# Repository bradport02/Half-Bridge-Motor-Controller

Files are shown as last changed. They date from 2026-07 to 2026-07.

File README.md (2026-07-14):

# Half-Bridge Motor Controller — Driven ESAC

A custom half-bridge motor controller designed for a GreenPower electric race car, built for the Driven Electric Student Automotive Competition (ESAC) team. Designed to replace the team's off-the-shelf PORTER-10 controller, which limits continuous current to ~10-20 A.

**Status: design complete (schematic + 4-layer KiCad PCB), not yet fabricated or bench-tested.**

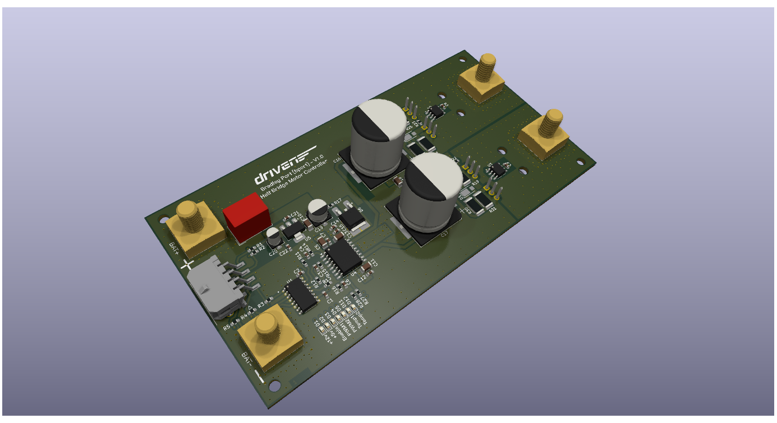
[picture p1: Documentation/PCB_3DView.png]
PCB 3D render

*3D render from KiCad — board has not yet been manufactured.*

## Purpose

Off-the-shelf controllers like the PORTER-10 are built for short current bursts and settle around 10-20 A continuous, which limits both acceleration off the line and sustained top speed. The goal was a controller capable of ~40 A continuous with a 120 A peak, giving the team a faster, more efficient motor drive and a platform that can be extended to regenerative braking in future.

## Target specification

- 120 A peak current draw
- ~40 A continuous draw
- 24 V system
- PWM input control
- On-board voltage regulation (24 V → 12 V → 5 V)

## How it works

The power stage is built around IRFB7440PbF N-channel MOSFETs (120 A rated), driven by a UCC21520 dual-channel gate driver. The UCC21520 takes PWM and control signals from a microcontroller and provides reinforced isolation between the low-voltage logic and the high-voltage power stage - protecting the control electronics from the transients typical of motor-drive environments. Its drive strength (4 A source / 6 A sink) is sized for fast, low-loss switching of the MOSFETs, and its programmable dead-time prevents shoot-through between high and low side.

Control interface:
- **PWM 1** — drive input
- **PWM 2** — regenerative braking input (architected for future use; not implemented in this revision. Both PWM inputs cannot be high simultaneously)
- **ENABLE** — logic-high enable

Signal isolation is handled by an ACSL-6400-50TE optocoupler for additional noise immunity.

## Connectors and I/O

- **Molex 43045-0806** — 8-pin signal input socket (PWM, enable, I²C, +12 V input)
- **Würth 7461098** — M8 metal lug connectors for battery and motor output, rated to 250 A

Two LM75 I²C temperature sensors monitor high-side and low-side MOSFET temperature, each with a programmable threshold that drives a status LED. The board has an onboard LED bank showing signal presence (PWM1/PWM2/Enable) and temperature-fault state at a glance.

## Voltage regulation

- **TSR-1-24120** steps 24 V down to 12 V, but only regulates correctly above ~15 V input.
- **UA78M05** regulates 12 V down to 5 V for logic.

**Known open item:** race telemetry shows battery voltage dropping below the TSR-1-24120's 15 V regulation floor during operation, which would drop the 12 V (and consequently 5 V) rail. A 12 V input pin is provided on the main connector as a workaround, but an external boost/always-available 12 V supply is the proposed fix and hasn't been implemented on this revision.

## PCB

Four-layer stack-up:
1. Power & signals
2. Continuous ground (noise isolation)
3. Ground & I²C
4. Power & signals

Specified for 2 oz copper on the outer layers for thermal dissipation, with extensive thermal vias. MOSFETs are oriented facing away from the board so they can be mounted to an external heatsink (as on the PORTER-10) rather than relying on the PCB alone for cooling.

Designed in KiCad across two schematic sheets — *Motor Controller* and *Power & Signals* — split for readability.

**This revision has no reverse-polarity protection.** This was a deliberate decision agreed with the ESAC team: the added complexity of full reverse-polarity protection at this current rating wasn't considered justified for this revision. BAT+ and BAT- are clearly marked on the silkscreen; correct wiring is required.

## Cost

Estimated production cost: **~£90/unit** (~£45 components, ~£45 PCB manufacture via JLCPCB). See the BOM for full component-level pricing.

## Future work

- Fabrication and bench testing of the current revision
- External 12 V supply to remove the low-battery-voltage regulation gap
- Regenerative braking implementation using the reserved PWM2 input

## Skills demonstrated

Power electronics design (MOSFET half-bridge, gate-drive isolation), 4-layer PCB design for high-current/thermal applications (KiCad), automotive/motorsport 12–24 V system design, I²C sensor integration, and BOM/cost engineering for a real production target.

## Author

Bradley Port — Designed for the Driven Electric Student Automotive Competition team.

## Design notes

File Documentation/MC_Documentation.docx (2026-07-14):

# Driven ESAC: Motor Controller

# Purpose:

Off the shelf motor controllers limit us as a team to how we can drive the motor. Typical controllers such as the PORTER-10 are designed to handle short current bursts but stabilise around 10/20amps. Our aim was to design a motor controller that would provide stable power at 40amps as well as have a peak current draw of 120amps. This will allow the car to accelerate off the line quicker but also maintain faster speeds. Additionally, designing a motor controller to our requirements allows us to be more efficient in how we drive the motor, but also add future functionality such as regenerative braking.

# Outcome:

After many conversations, we came up with a list of requirements and ultimately a specification to build the motor controller to. Some of the aims were:

- 120A peak current draw.
- ~40A continuous draw.
- Works with a 24v system.
- PWM input to control the motor.
- On-board voltage regulation.

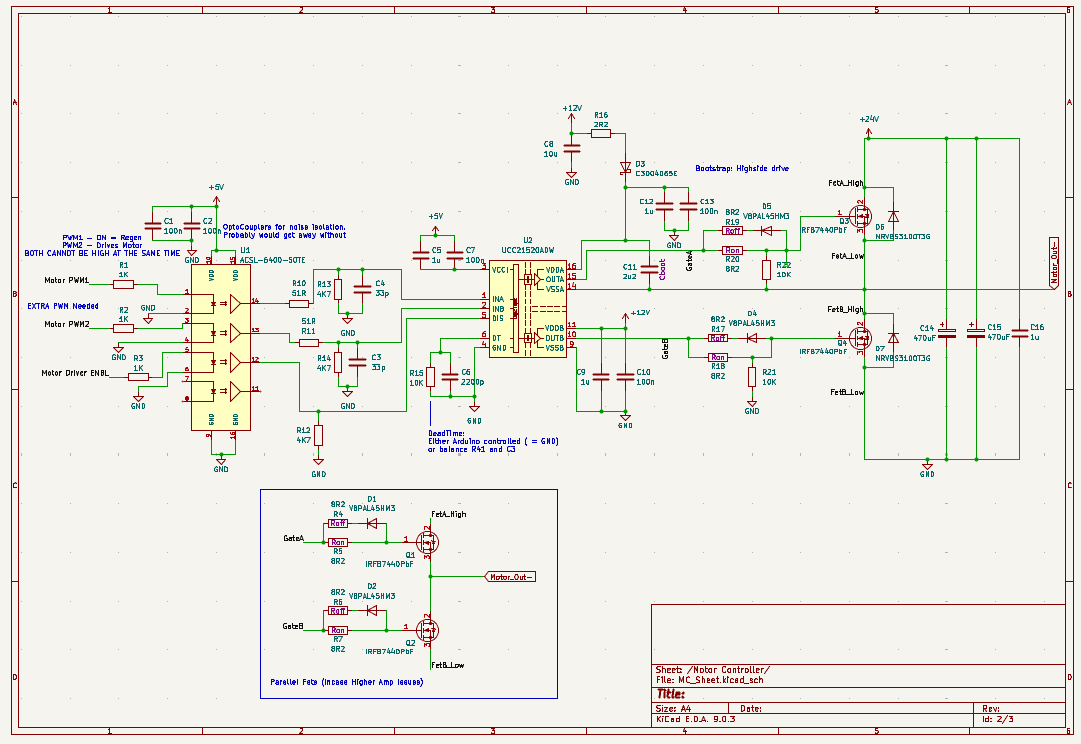
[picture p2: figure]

With these requirements, we build the following schematic.

## Key Components:

- UCC12520 Dual-Channel Gate Driver.
- ACSL-6400-50TE OptoCoupler.
- IRFB7440PbF 120A Mosfets

# How it works:

This motor controller circuit is designed to drive the motor in the driven race car, utilising the UCC21520 isolated gate driver and IFBN7440PbF N-channel MOSFETs. The UCC21520 receives PWM and control signals from a microcontroller and provides reinforced isolation between the low-voltage logic and high-voltage power stages, ensuring robust protection against the electrical transients, which are common in motor control environments. Its high current drive capability (4A source, 6A sink) enables fast and efficient switching of the IFBN7440PbF, which is optimized for low RDS and rapid response. This is critical for delivering precise torque and speed control when under dynamic racing conditions. The gate driver's programmable dead-time feature prevents shoot-through during switching, while its fast propagation delay supports high-frequency PWM for precise motor control. The signals required to drive this motor controller are:

- PWM 1 (INPUT A)
- PWM 2 (INPUT B)
- ENABLE (LOGIC HIGH)

# IO:

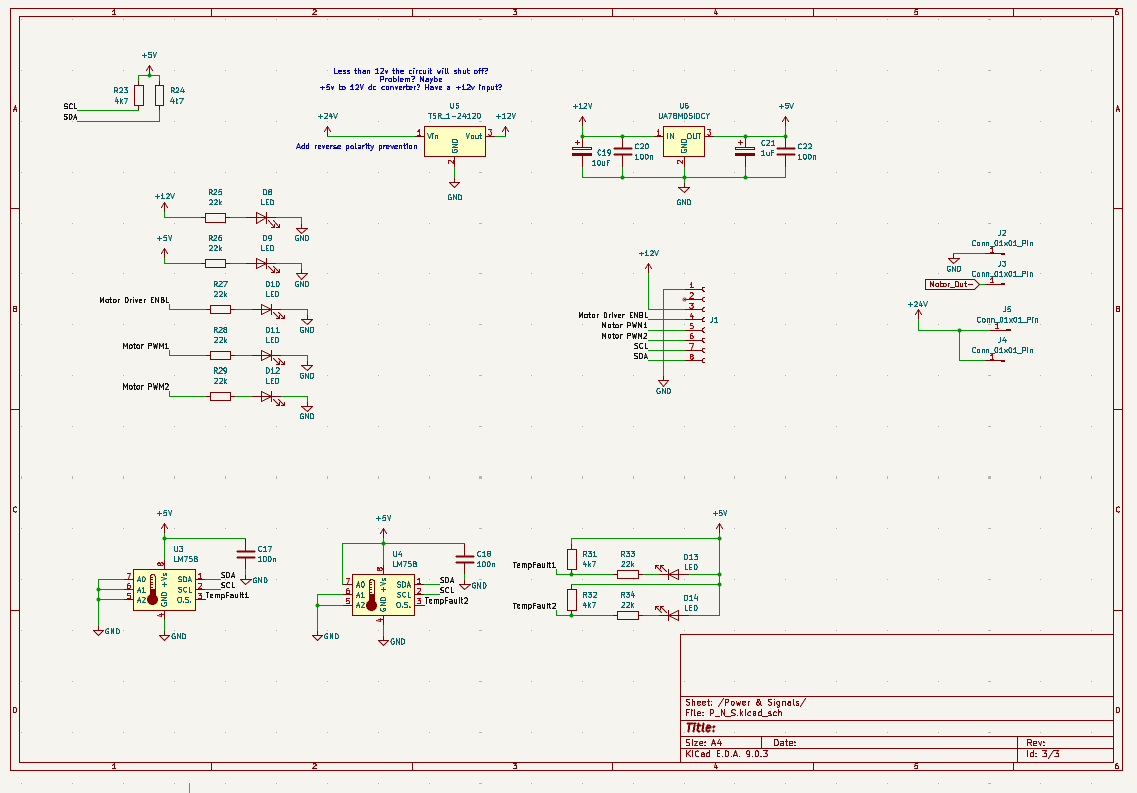
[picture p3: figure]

## Connectors:

MOLEX 43045-0806: 8 pin socket, this is where all the main inputs are provided to the board.

Wurth 7461098: M8 metal lug connections, allow the high-current connections from the battery and output to the motor. These can handle up to 250A.

## I2C:

The 8 pin socket (J1)has two inputs for the I2C signals, SCL (7) and SDA (8). These signals allow the two LM75 temperature sensors to be connected to the Arduino. The purpose of these is to provide a precise temperature of how hot the high and low side MOSFETs are. The LM75 can be programmed to have a threshold temperature in which an LED will illuminate.

## Voltage Regulation:

The board is designed to have an onboard TSR-1-24120 voltage regulator to step down the +24v to +12v. However, this IC only regulates when the input voltage is greater than +15v. From race data, it can be seen that the battery voltages drop well below this, I propose that there is an external voltage step up that can always provide +12v to the motor controller. Pin 3 on Connector J1 has a +12v input.

The +5v will always be regulated as long as there is a +12v rail present. The 5v regulator is a UA78M05.

# PCB:

The PCB has a four layer stack up:

1. Power & Signals.
2. Continuous Ground (Noise Isolation)
3. Ground and I2C.
4. Power and Signals.

The board MUST be manufactured with a 2Oz copper outer layers. This will help with thermal dissipation and is what the board has been designed to handle. The PCB has been designed to be as thermally efficient as possible, with many thermal vias. The MOSFETS face away from the PCB, so that they can be mounted to an external heatsink and keep the board cooler. See the PORTER-10 for an example. A sufficient heatsink will need to be manufactured.

THIS PCB HAS NO REVERSE POLARITY PROTECTION. From discussions with the ESAC Team we felt that the necessary complexity of protecting this device from reverse polarity was not required. Please take caution when powering this device and ensure that is has been wired correctly. There is BAT+ and BAT- labels as well as big ‘+’ and ‘-‘ idents on the silkscreen.

## Layer Stackup:

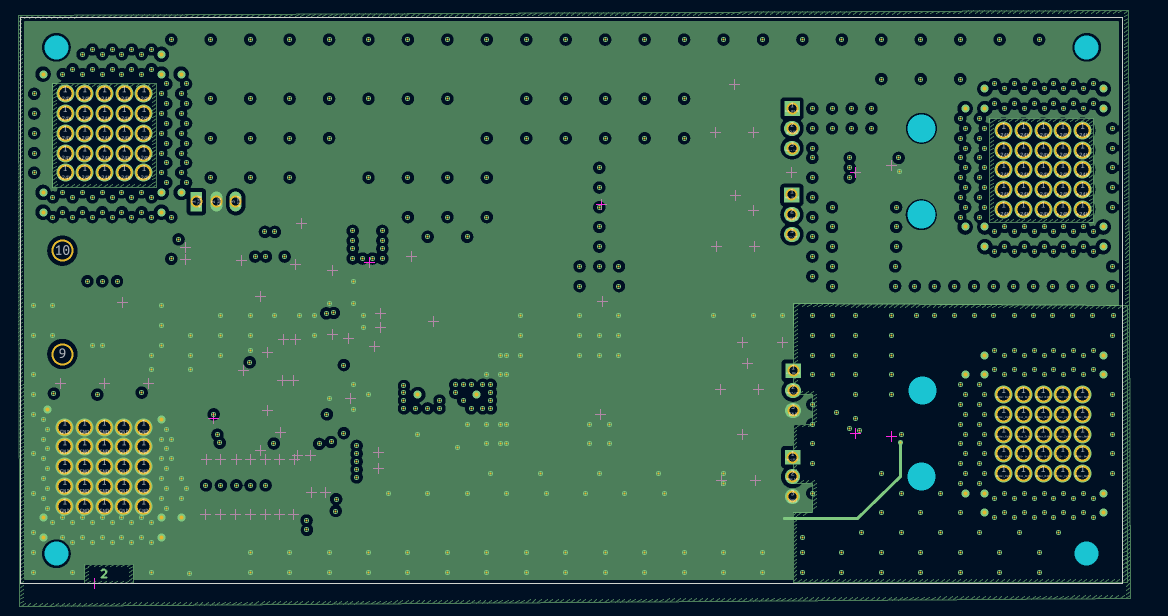
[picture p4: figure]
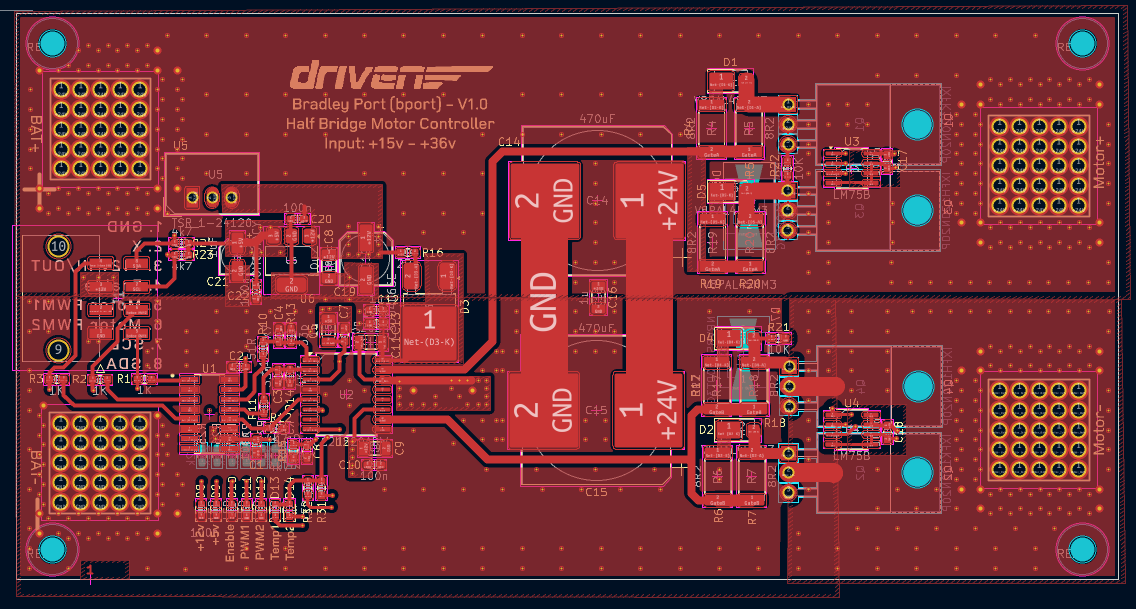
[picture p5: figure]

Layer 1:

Layer 2:

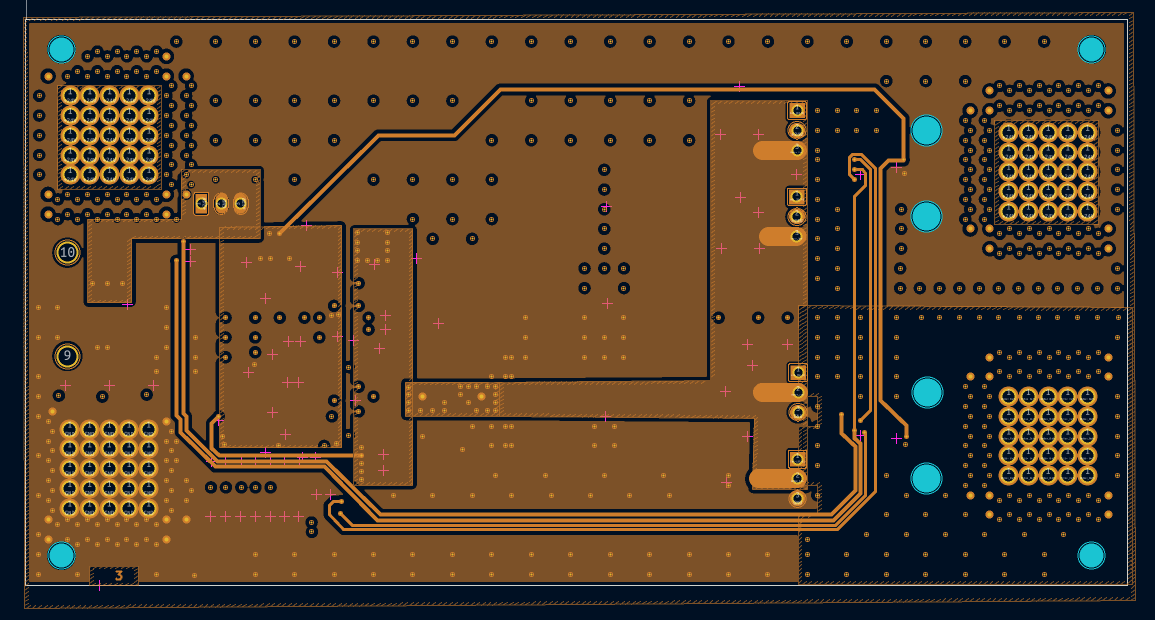
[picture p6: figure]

Layer 3:

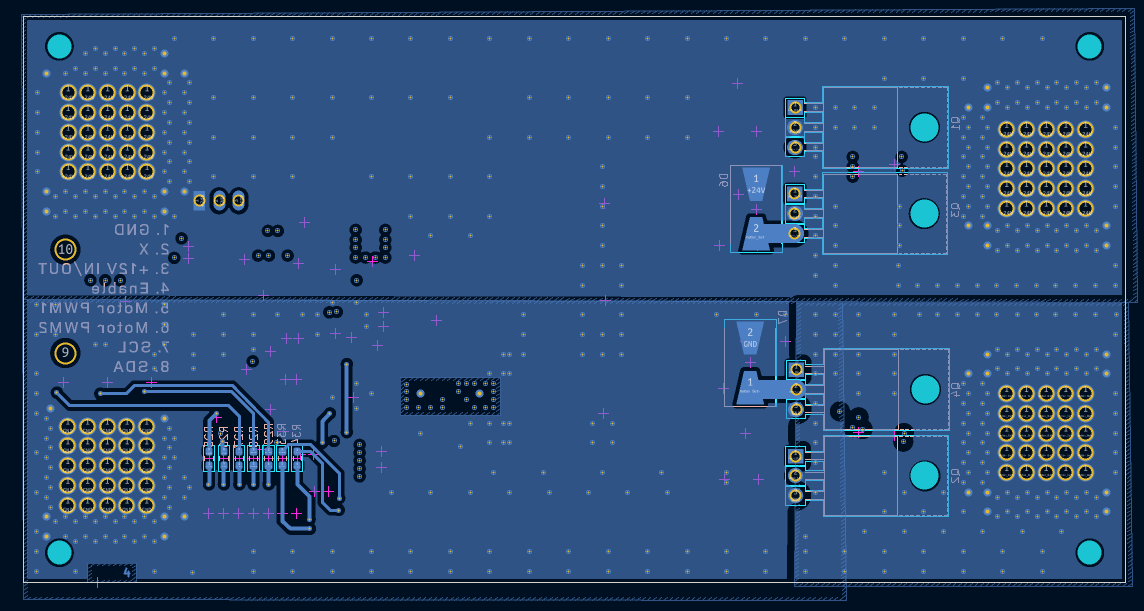
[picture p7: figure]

Layer 4:

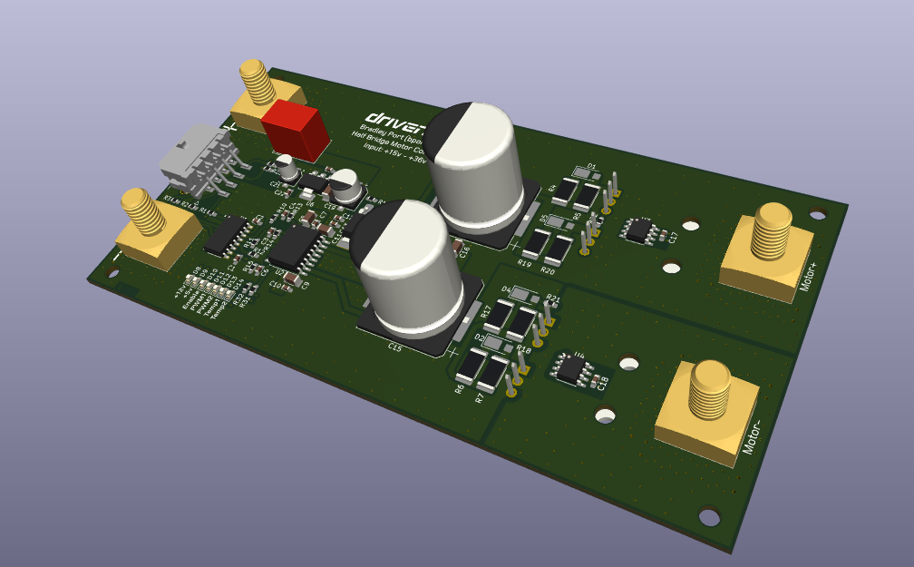
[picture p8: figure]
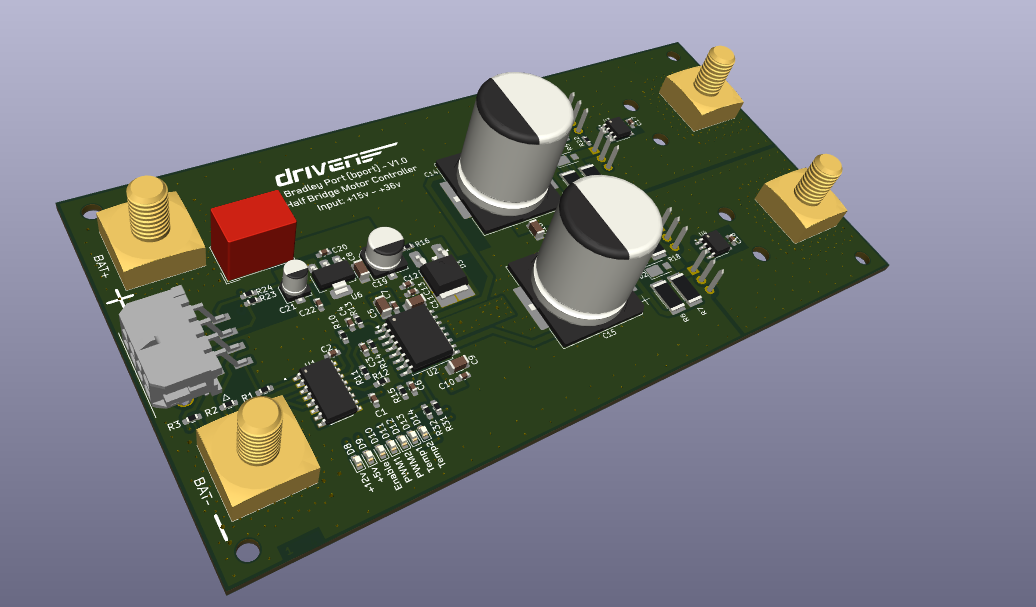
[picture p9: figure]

In the bottom left corner of the PCB there is a bank of LEDs that detail all of the signal status. When the LEDs are illuminated, it means that the signals are present. The TEMP1 and TEMP2 LEDS will illuminate when the temperature read by the LM75 is above the programmed value.

# Overview:

This board was designed in KiCAD. There are two schematic sheets, ‘Motor Controller’ and ‘Power & Signals’. Each section is split into these two sheets to make it easier to navigate.

The motor controller is a good addition to the Driven Race Car as it will allow the ESAC team to provide precise motor control as well as a future proof device if regenerative braking is added in the future.

The BOM outlines a rough production cost of £90. This consists of £45 in components and £45 to manufacture the PCB with JLR PCB. Please refer to the BOM excel sheet for more precise details.

ESAC Motor Controller V1.0 Bradley Port (bport)

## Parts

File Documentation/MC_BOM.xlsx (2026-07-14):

Reference | Qty | Value | Footprint | Datasheet | Vendor | Price (Per Component) | Price (Total)
C1,C2,C7,C8,C9,C12,C15,C21,C22 | 9 | 100n | Capacitor_SMD:C_0603_1608Metric_Pad1.08x0.95mm_HandSolder | ~ | RS Components (https://uk.rs-online.com/web/p/mlccs-multilayer-ceramic-capacitors/2477743?gb=s) | £0.092 | £0.828
C3,C4 | 2 | 33p | Capacitor_SMD:C_0603_1608Metric_Pad1.08x0.95mm_HandSolder | ~ | RS Components (https://uk.rs-online.com/web/p/mlccs-multilayer-ceramic-capacitors/1356551?gb=s) | £0.079 | £0.158
C5,C11,C18 | 3 | 1u | Capacitor_SMD:C_1206_3216Metric | ~ | RS Components (https://uk.rs-online.com/web/p/mlccs-multilayer-ceramic-capacitors/6480733?gb=s) | £0.071 | £0.213
C6 | 1 | 2200p | Capacitor_SMD:C_0603_1608Metric_Pad1.08x0.95mm_HandSolder | ~ | RS Components (https://uk.rs-online.com/web/p/mlccs-multilayer-ceramic-capacitors/2477850?gb=s) | £0.068 | £0.068
C10 | 1 | 10u | Capacitor_SMD:C_1206_3216Metric_Pad1.33x1.80mm_HandSolder | ~ | RS Components (https://uk.rs-online.com/web/p/mlccs-multilayer-ceramic-capacitors/2608849?gb=s) | £0.270 | £0.270
C13 | 1 | 2u2 | Capacitor_SMD:C_1206_3216Metric | ~ | RS Components (https://uk.rs-online.com/web/p/mlccs-multilayer-ceramic-capacitors/6911215P?gb=s) | £0.140 | £0.140
C14 | 1 | 1u | Capacitor_SMD:C_0603_1608Metric_Pad1.08x0.95mm_HandSolder | ~ | RS Components (https://uk.rs-online.com/web/p/mlccs-multilayer-ceramic-capacitors/9155799?gb=s) | £0.084 | £0.084
C16,C17 | 2 | 470uF | Capacitor_SMD:CP_Elec_18x22 | ~ | RS Components (https://uk.rs-online.com/web/p/aluminium-capacitors/7083737?gb=s) | £1.310 | £2.620
C19 | 1 | 10uF | Capacitor_SMD:CP_Elec_6.3x5.8 | ~ | RS Components (https://uk.rs-online.com/web/p/aluminium-capacitors/5370809?gb=s) | £0.366 | £0.366
C20 | 1 | 1uF | Capacitor_SMD:CP_Elec_4x5.8 | ~ | RS Components (https://uk.rs-online.com/web/p/aluminium-capacitors/5370815?gb=s) | £0.208 | £0.208
D1,D2,D3,D4,D5,D11,D12 | 7 | LED | LED_SMD:LED_0603_1608Metric | ~ | RS Components (https://uk.rs-online.com/web/p/leds/2790665?gb=s) | £0.116 | £0.812
D6 | 1 | C3D04065E | Package_TO_SOT_SMD:TO-252-2_TabPin1 | https://www.wolfspeed.com/media/downloads/124/C3D04065E.pdf | Mouser (https://www.mouser.co.uk/ProductDetail/Wolfspeed/C3D04065E?qs=hPK38Qhkn9UoTiWADRClGQ%3D%3D) | £2.010 | £2.010
D7,D8 | 2 | V8PAL45HM3 | Diode_SMD:Vishay_SMPA | https://docs.rs-online.com/6f61/0900766b8133de80.pdf | RS Components (https://uk.rs-online.com/web/p/schottky-diodes-rectifiers/8306211P?gb=s) | £0.419 | £0.838
D9,D10 | 2 | NRVBS3100T3G | Diode_SMD:D_SMB-SMC_Universal_Handsoldering | https://docs.rs-online.com/6b4b/0900766b812212e2.pdf | RS Components (https://uk.rs-online.com/web/p/schottky-diodes-rectifiers/7811131?gb=s) | £0.509 | £1.018
J1 | 1 | Conn_01x08_Socket | 43045-0806:43045-08YY_060708_1 | ~ | Mouser (https://www.mouser.co.uk/ProductDetail/Molex/43045-0806?qs=MGlPTwjtJ4aUv0CnPCSCgA%3D%3D) | £2.640 | £2.640
J2,J3,J4,J5 | 4 | Conn_01x01_Pin | 7461099:7461098 | ~ | RS Components (https://uk.rs-online.com/web/p/screw-terminals/1224992?gb=s) | £3.630 | £14.520
Q1,Q2 | 2 | IXFK120N20P | Package_TO_SOT_THT:TO-220-3_Horizontal_TabUp | http://www.irf.com/product-info/datasheets/data/irlz44n.pdf | Already Purchased |  | £0.000
Q3,Q4 | 2 | IXFH120N20P | Package_TO_SOT_THT:TO-220-3_Horizontal_TabUp | http://www.irf.com/product-info/datasheets/data/irlz44n.pdf | Already Purchased |  | £0.000
R1,R2,R13,R14,R15,R27,R28 | 7 | 4k7 | Resistor_SMD:R_0603_1608Metric_Pad0.98x0.95mm_HandSolder | ~ | RS Components (https://uk.rs-online.com/web/p/surface-mount-resistors/2284870?gb=s) | £0.024 | £0.168
R3,R4,R5 | 3 | 1K | Resistor_SMD:R_0603_1608Metric_Pad0.98x0.95mm_HandSolder | ~ | RS Components (https://uk.rs-online.com/web/p/surface-mount-resistors/1995479?gb=s) | £0.006 | £0.018
R6,R7,R8,R9,R10,R26,R29 | 7 | 22k | Resistor_SMD:R_0603_1608Metric_Pad0.98x0.95mm_HandSolder | ~ | RS Components (https://uk.rs-online.com/web/p/surface-mount-resistors/2284828?gb=s) | £0.024 | £0.168
R11,R12 | 2 | 51R | Resistor_SMD:R_0603_1608Metric_Pad0.98x0.95mm_HandSolder | ~ | Mouser (https://www.mouser.co.uk/ProductDetail/YAGEO/AR0603JR-0751RL) | £0.095 | £0.190
R16,R22,R23 | 3 | 10K | Resistor_SMD:R_0603_1608Metric_Pad0.98x0.95mm_HandSolder | ~ | RS Components (https://uk.rs-online.com/web/p/surface-mount-resistors/2413294?gb=s) | £0.184 | £0.552
R17 | 1 | 2R2 | Resistor_SMD:R_0603_1608Metric_Pad0.98x0.95mm_HandSolder | ~ | RS Components (https://www.mouser.co.uk/ProductDetail/TE-Connectivity-Holsworthy/CRGS0603J2R2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) | £0.072 | £0.072
R18,R19,R20,R21 | 4 | 8R2 | Resistor_SMD:R_2512_5025Metric_Pad1.40x2.65mm_HandSolder | ~ | RS Components (https://uk.rs-online.com/web/p/surface-mount-resistors/8711048?gb=s) | £0.538 | £2.152
U1 | 1 | ACSL-6400-50TE | ACSL-6400:SOIC127P599X172-16N |  | RS Components (https://uk.rs-online.com/web/p/optocouplers/2305323?gb=s) | £5.420 | £5.420
U2,U3 | 2 | LM75B | Package_SO:SOIC-8_3.9x4.9mm_P1.27mm | http://www.ti.com/lit/ds/symlink/lm75b.pdf | RS Components (https://uk.rs-online.com/web/p/temperature-humidity-sensor-ics/1962011?gb=s) | £0.540 | £1.080
U4 | 1 | UCC21520ADW | Package_SO:SOIC-16W_7.5x10.3mm_P1.27mm | http://www.ti.com/lit/ds/symlink/ucc21520.pdf | Mouser (https://www.mouser.co.uk/ProductDetail/Texas-Instruments/UCC21520ADWR?qs=%2FP2Ij7fVdhFF4LbWbpIJ1w%3D%3D) | £3.380 | £3.380
U5 | 1 | UA78M05IDCY | Package_TO_SOT_SMD:SOT-223-3_TabPin2 | https://www.ti.com/lit/gpn/UA78M-Q1 | RS Components (https://uk.rs-online.com/web/p/voltage-regulators/6616730?gb=s) | £0.504 | £0.504
U6 | 1 | TSR_1-24120 | Converter_DCDC:Converter_DCDC_TRACO_TSR-1_THT | http://www.tracopower.com/products/tsr1.pdf | RS Components (https://uk.rs-online.com/web/p/switching-regulators/6664385?gb=s) | £5.040 | £5.040
PCB | 1 | JLCPCB 5x | 2oz Copper, 4 layer board. |  | JLCPCB | £45.87 | £45.870
 |  |  |  |  |  | Total | £91.407

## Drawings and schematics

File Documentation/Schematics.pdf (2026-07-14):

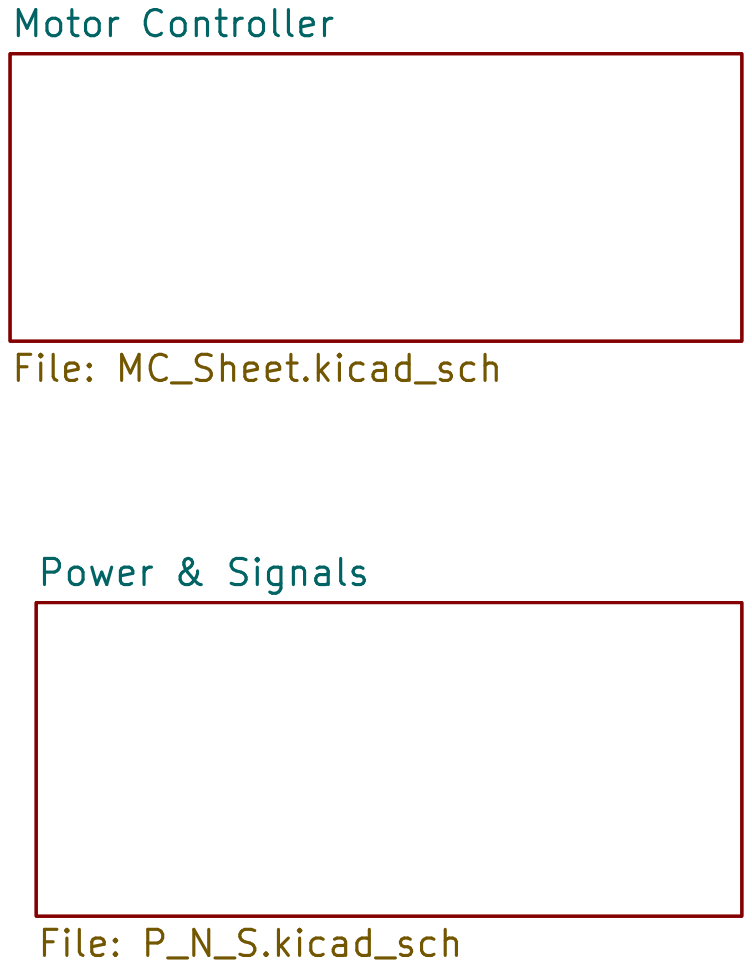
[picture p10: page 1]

Motor Controller File: MC_Sheet.kicad_sch Power & Signals File: P_N_S.kicad_sch

Id: 1/3 Title: File: MC.kicad_sch Sheet: /

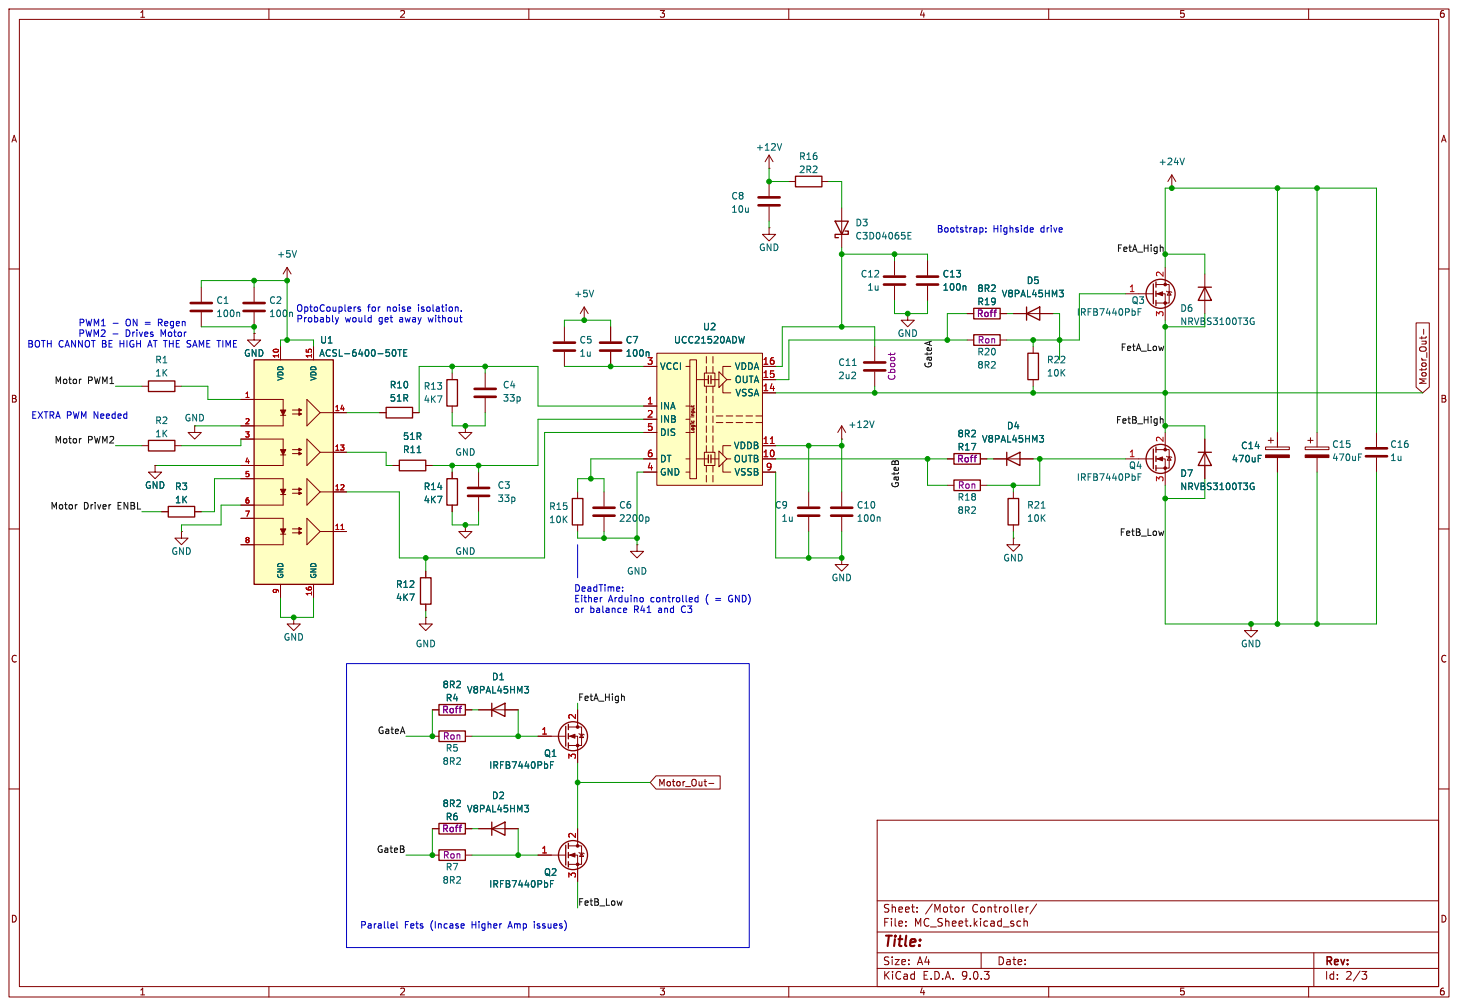
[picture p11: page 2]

8R2 Roff Logic Input VCCI 3

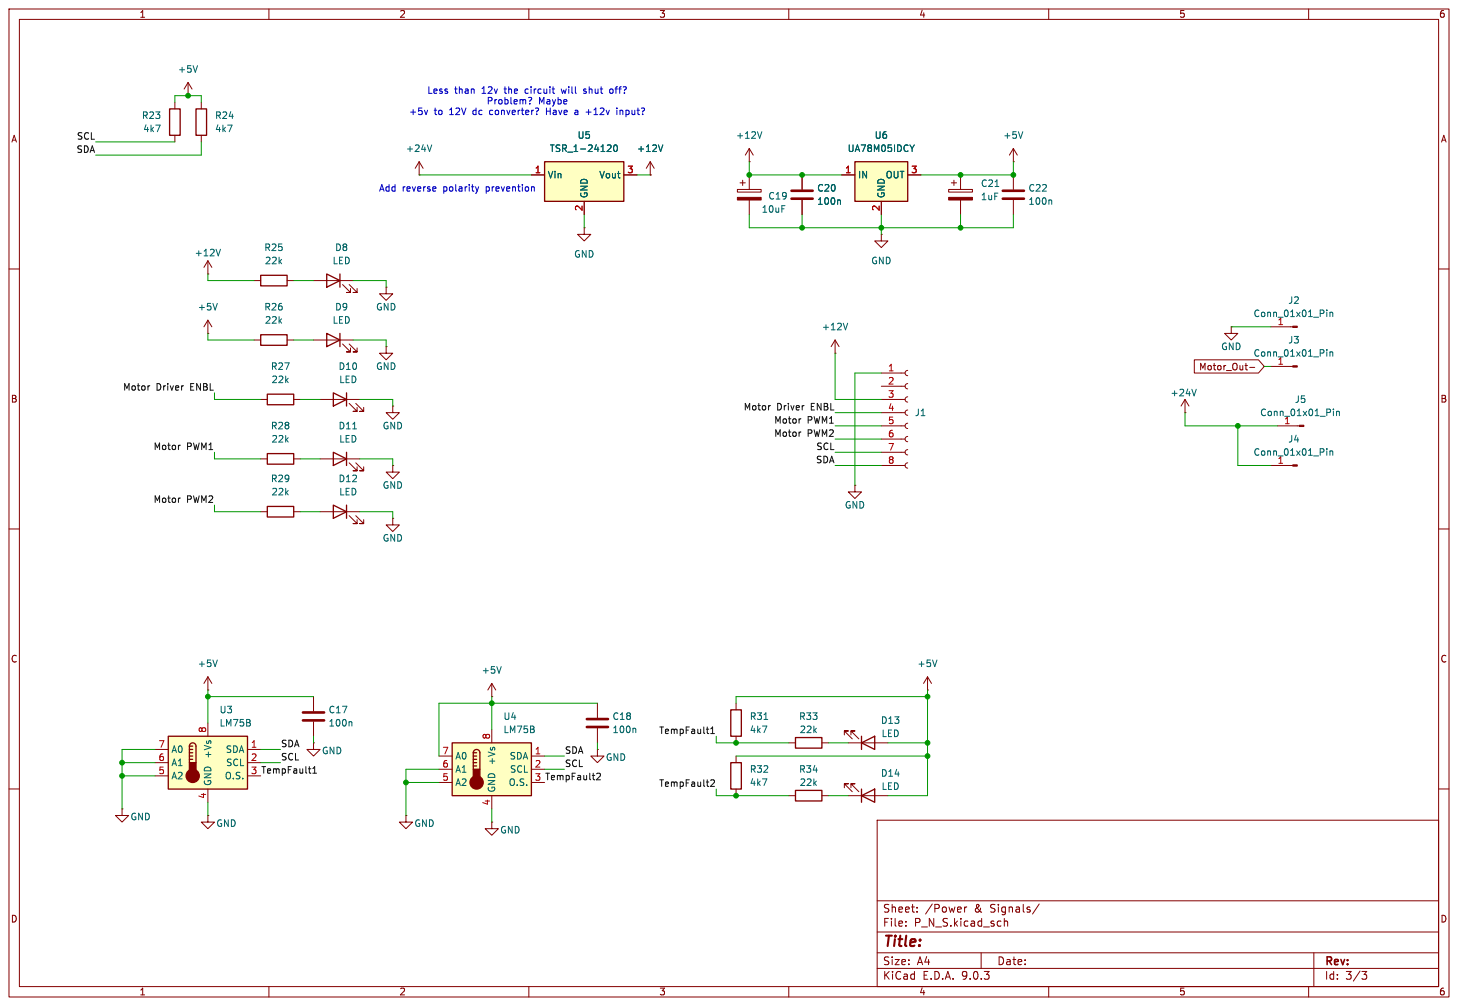
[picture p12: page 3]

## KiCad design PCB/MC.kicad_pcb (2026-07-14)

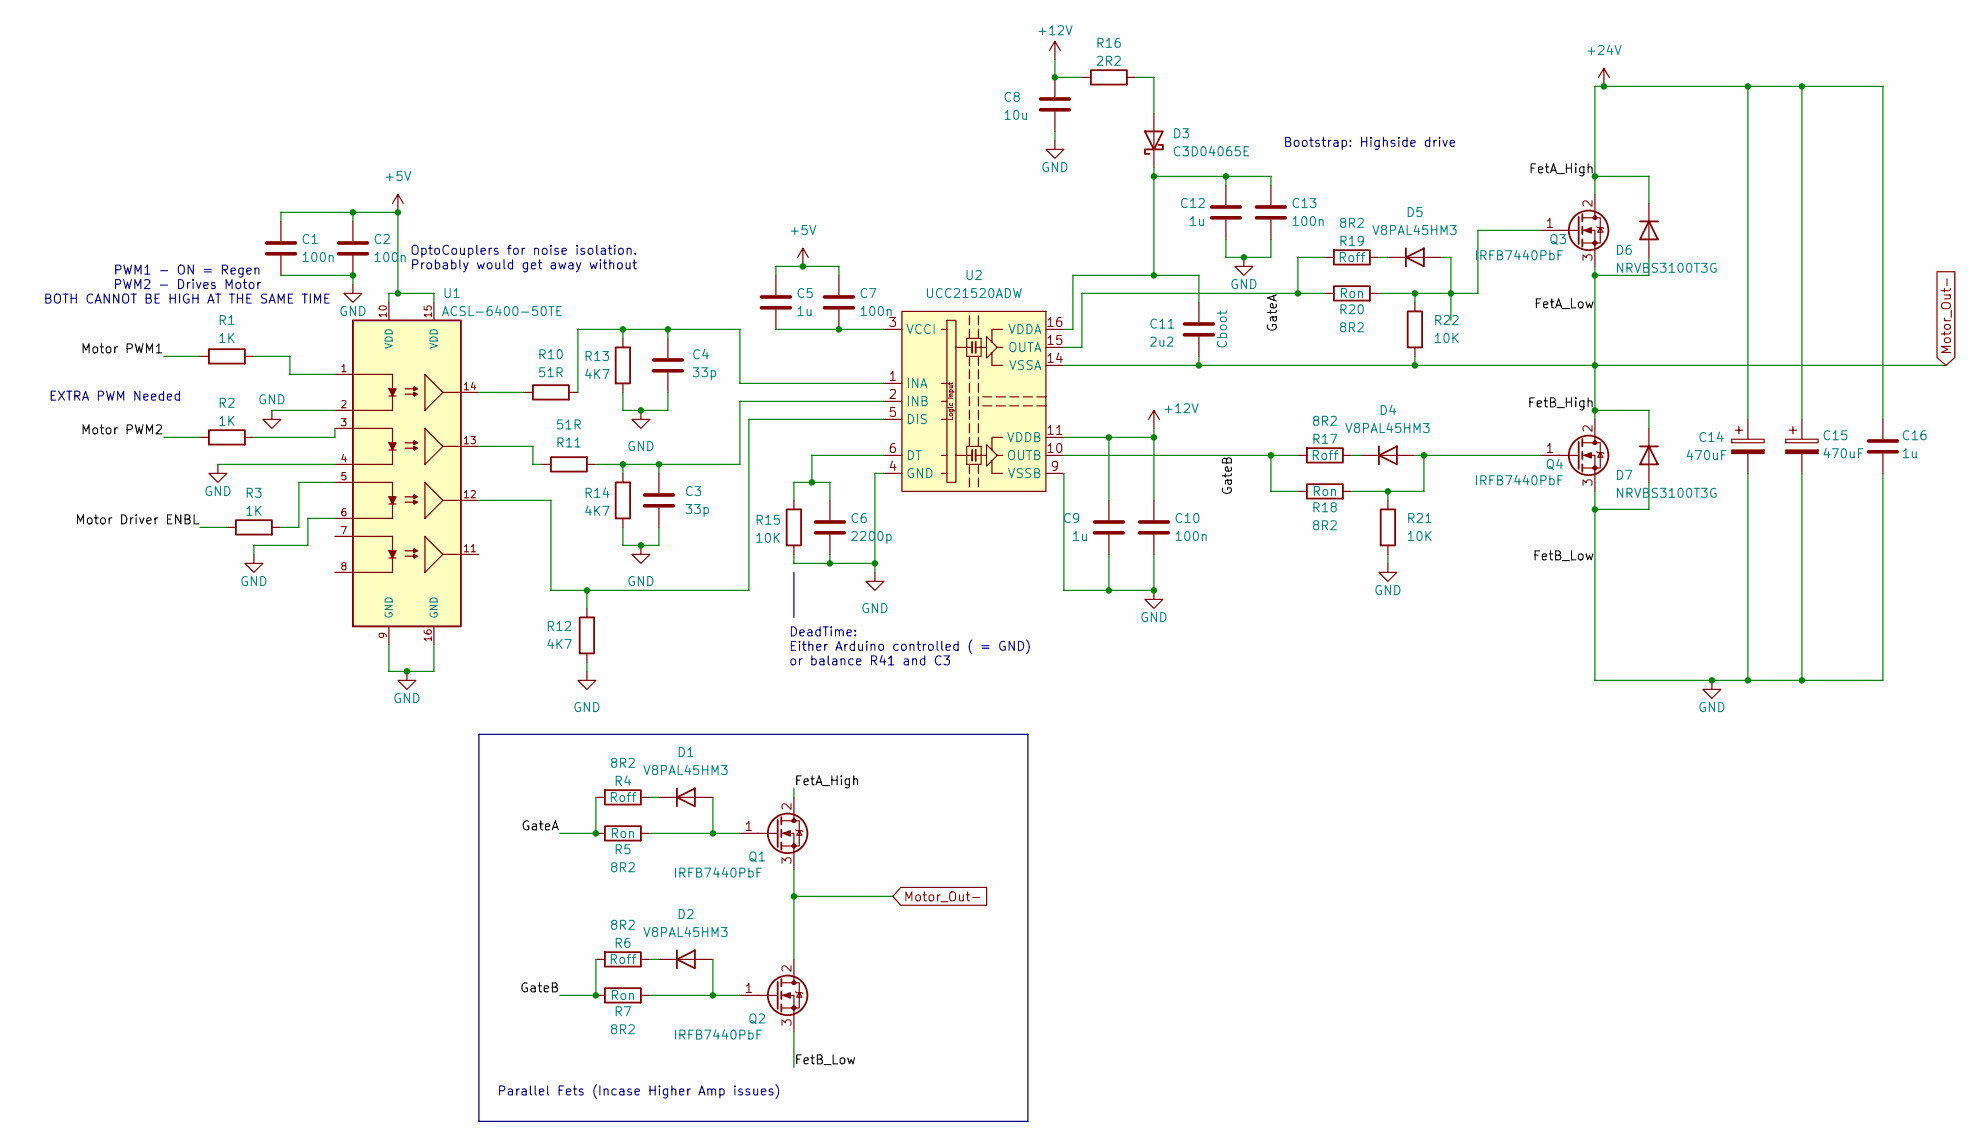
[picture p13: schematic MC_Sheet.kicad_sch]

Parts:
C1, C2, C7, C10, C13: 100n; C_0603_1608Metric_Pad1.08x0.95mm_HandSolder
C3, C4: 33p; C_0603_1608Metric_Pad1.08x0.95mm_HandSolder
C5, C9, C16: 1u; C_1206_3216Metric
C6: 2200p; C_0603_1608Metric_Pad1.08x0.95mm_HandSolder
C8: 10u; C_1206_3216Metric_Pad1.33x1.80mm_HandSolder
C11: 2u2; C_1206_3216Metric
C12: 1u; C_0603_1608Metric_Pad1.08x0.95mm_HandSolder
C14, C15: 470uF; CP_Elec_18x22
D1, D2, D4, D5: V8PAL45HM3; Vishay_SMPA
D3: C3D04065E; TO-252-2_TabPin1
D6, D7: NRVBS3100T3G; D_SMB-SMC_Universal_Handsoldering
Q1, Q2, Q3, Q4: IRFB7440PbF; TO-220-3_Horizontal_TabUp
R1, R2, R3: 1K; R_0603_1608Metric_Pad0.98x0.95mm_HandSolder
R4, R5, R6, R7, R17, R18, R19, R20: 8R2; R_2512_6332Metric_Pad1.40x3.35mm_HandSolder
R10, R11: 51R; R_0603_1608Metric_Pad0.98x0.95mm_HandSolder
R12, R13, R14: 4K7; R_0603_1608Metric_Pad0.98x0.95mm_HandSolder
R15, R21, R22: 10K; R_0603_1608Metric_Pad0.98x0.95mm_HandSolder
R16: 2R2; R_0603_1608Metric_Pad0.98x0.95mm_HandSolder
U1: ACSL-6400-50TE; SOIC127P599X172-16N; PARTREV August 21 2018
U2: UCC21520ADW; SOIC-16W_7.5x10.3mm_P1.27mm

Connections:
+5V: C1.1, C2.1, C5.1, C7.1, U1.10 (VDD), U1.15 (VDD); also elsewhere on the board
+12V: C8.1, C9.1, C10.1, R16.1, U2.11 (VDDB); also elsewhere on the board
+24V: C14.1, C15.1, C16.1, D6.1 (K), Q1.2 (D), Q3.2 (D); also elsewhere on the board
/Motor Controller/GateA: R4.2, R5.1, R19.2, R20.1, U2.15 (OUTA)
/Motor Controller/GateB: R6.2, R7.1, R17.2, R18.1, U2.10 (OUTB)
/Power & Signals/Motor Driver ENBL: R3.1; also elsewhere on the board
/Power & Signals/Motor PWM1: R1.1; also elsewhere on the board
/Power & Signals/Motor PWM2: R2.1; also elsewhere on the board
GND: C1.2, C2.2, C3.2, C4.2, C6.2, C8.2, C9.2, C10.2, C12.2, C13.2, C14.2, C15.2, C16.2, D7.2 (A), Q2.3 (S), Q4.3 (S), R12.2, R13.2, R14.2, R15.2, R21.2, U1.2, U1.4, U1.6, U1.9 (GND), U1.16 (GND), U2.4 (GND), U2.9 (VSSB); also elsewhere on the board
Motor_Out-: C11.2, D6.2 (A), D7.1 (K), Q1.3 (S), Q2.2 (D), Q3.3 (S), Q4.2 (D), R22.2, U2.14 (VSSA); also elsewhere on the board
unnamed: C5.2, C7.2, U2.3 (VCCI), U2.8 (VCCI)
unnamed: D1.2 (A), Q1.1 (G), R5.2
unnamed: D1.1 (K), R4.1
unnamed: D2.2 (A), Q2.1 (G), R7.2
unnamed: D2.1 (K), R6.1
unnamed: D3.2 (A), R16.2
unnamed: C11.1, C12.1, C13.1, D3.1 (K), U2.16 (VDDA)
unnamed: D4.2 (A), Q4.1 (G), R18.2, R21.1
unnamed: D4.1 (K), R17.1
unnamed: D5.2 (A), Q3.1 (G), R20.2, R22.1
unnamed: D5.1 (K), R19.1
unnamed: R1.2, U1.1
unnamed: R2.2, U1.3
unnamed: R3.2, U1.5
unnamed: R10.1, U1.14
unnamed: R11.1, U1.13
unnamed: R12.1, U1.12, U2.5 (DIS)
unnamed: C6.1, R15.1, U2.6 (DT)
unnamed: C4.1, R10.2, R13.1, U2.1 (INA)
unnamed: C3.1, R11.2, R14.1, U2.2 (INB)

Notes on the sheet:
Bootstrap: Highside drive
EXTRA PWM Needed
OptoCouplers for noise isolation. Probably would get away without
Parallel Fets (Incase Higher Amp issues)
PWM1 - ON = Regen PWM2 - Drives Motor BOTH CANNOT BE HIGH AT THE SAME TIME
DeadTime: Either Arduino controlled ( = GND) or balance R41 and C3

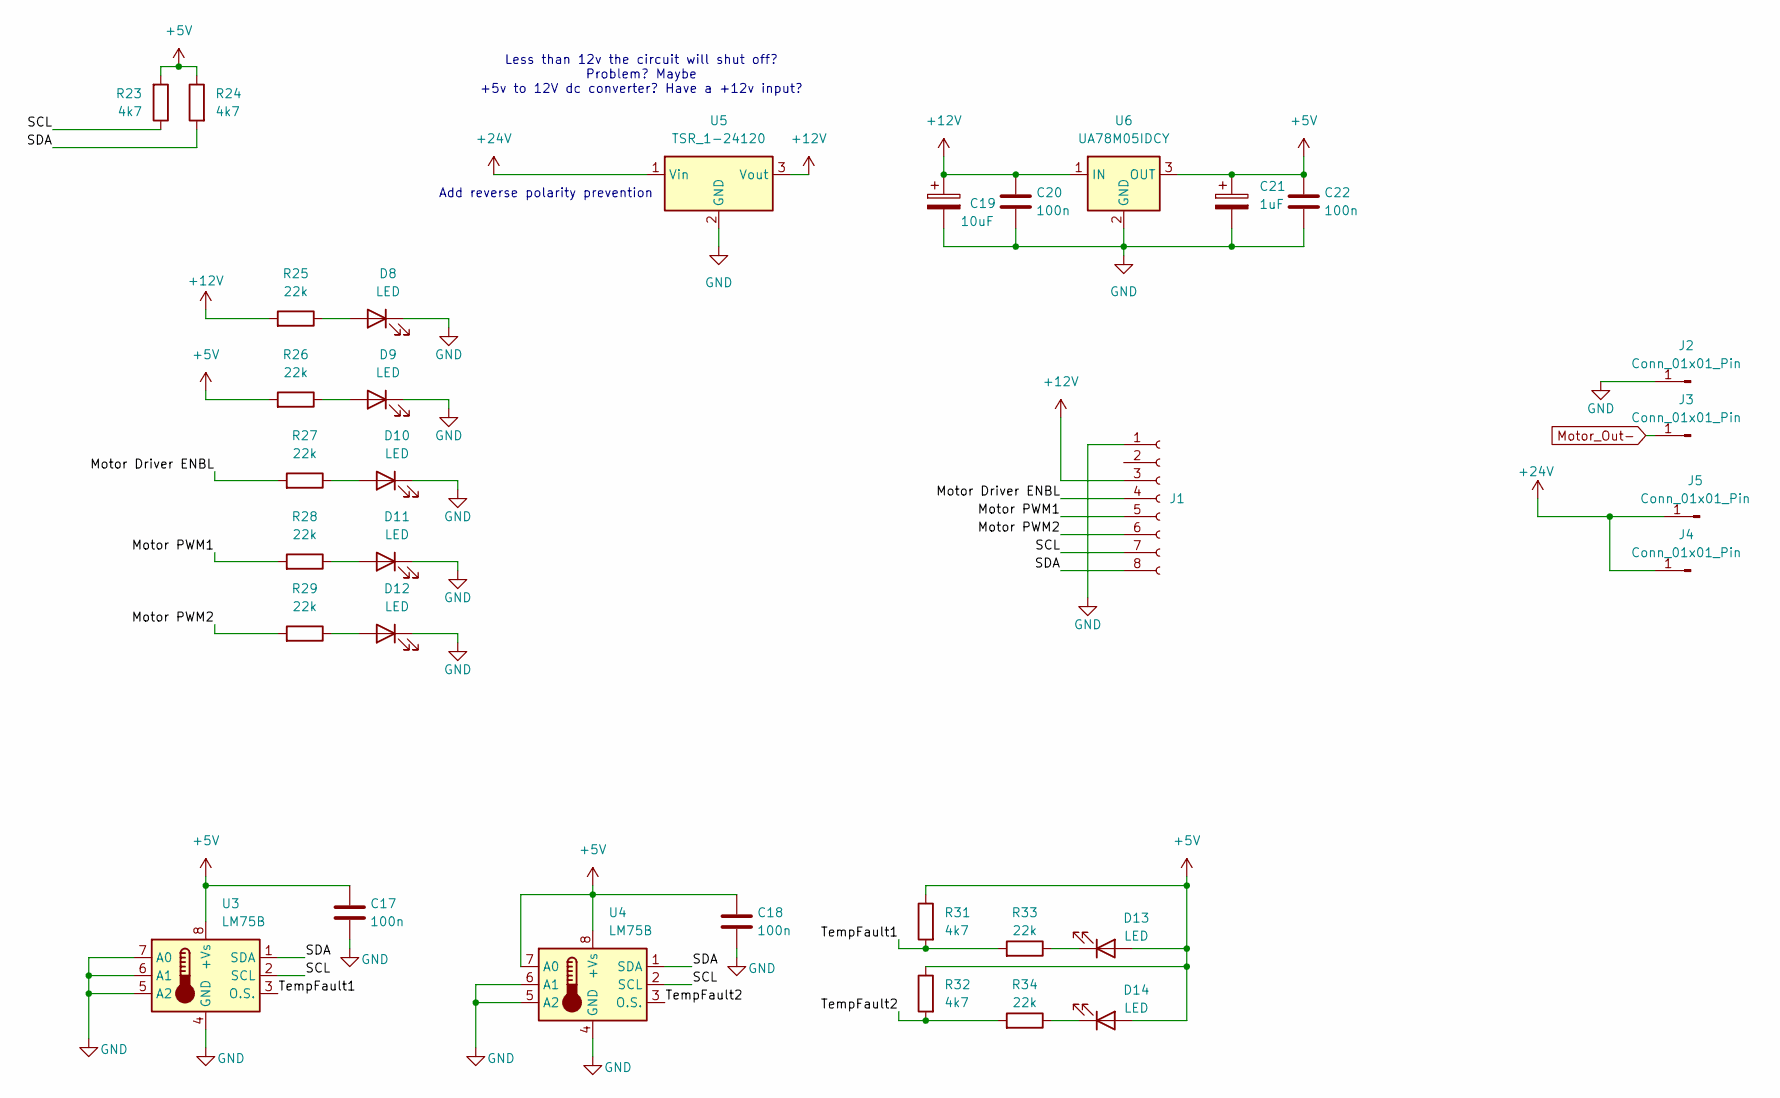
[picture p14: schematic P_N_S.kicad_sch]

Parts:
C17, C18, C20, C22: 100n; C_0603_1608Metric_Pad1.08x0.95mm_HandSolder
C19: 10uF; CP_Elec_6.3x5.8
C21: 1uF; CP_Elec_4x5.8
D8, D9, D10, D11, D12, D13, D14: LED; LED_0603_1608Metric
J1: Conn_01x08_Socket; 43045-08YY_060708_1
J2, J3, J4, J5: Conn_01x01_Pin; 7461098
R23, R24, R31, R32: 4k7; R_0603_1608Metric_Pad0.98x0.95mm_HandSolder
R25, R26, R27, R28, R29, R33, R34: 22k; R_0603_1608Metric_Pad0.98x0.95mm_HandSolder
U3, U4: LM75B; SOIC-8_3.9x4.9mm_P1.27mm
U5: TSR_1-24120; Converter_DCDC_TRACO_TSR-1_THT
U6: UA78M05IDCY; SOT-223-3_TabPin2

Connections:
+5V: C17.1, C18.1, C21.1, C22.1, D13.2 (A), D14.2 (A), R23.2, R24.1, R26.2, R31.1, R32.1, U3.8 (+Vs), U4.7 (A0), U4.8 (+Vs), U6.3 (OUT); also elsewhere on the board
+12V: C19.1, C20.1, J1.3, R25.2, U5.3 (Vout), U6.1 (IN); also elsewhere on the board
+24V: J4.1, J5.1, U5.1 (Vin); also elsewhere on the board
/Power & Signals/Motor Driver ENBL: J1.4, R27.2; also elsewhere on the board
/Power & Signals/Motor PWM1: J1.5, R28.2; also elsewhere on the board
/Power & Signals/Motor PWM2: J1.6, R29.2; also elsewhere on the board
/Power & Signals/SCL: J1.7, R23.1, U3.2 (SCL), U4.2 (SCL)
/Power & Signals/SDA: J1.8, R24.2, U3.1 (SDA), U4.1 (SDA)
/Power & Signals/TempFault1: R31.2, R33.2, U3.3 (O.S.)
/Power & Signals/TempFault2: R32.2, R34.2, U4.3 (O.S.)
GND: C17.2, C18.2, C19.2, C20.2, C21.2, C22.2, D8.1 (K), D9.1 (K), D10.1 (K), D11.1 (K), D12.1 (K), J1.1, J2.1, U3.4 (GND), U3.5 (A2), U3.6 (A1), U3.7 (A0), U4.4 (GND), U4.5 (A2), U4.6 (A1), U5.2 (GND), U6.2 (GND); also elsewhere on the board
Motor_Out-: J3.1; also elsewhere on the board
unnamed: D8.2 (A), R25.1
unnamed: D9.2 (A), R26.1
unnamed: D10.2 (A), R27.1
unnamed: D11.2 (A), R28.1
unnamed: D12.2 (A), R29.1
unnamed: D13.1 (K), R33.1
unnamed: D14.1 (K), R34.1

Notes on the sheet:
Less than 12v the circuit will shut off? Problem? Maybe +5v to 12V dc converter? Have a +12v input?
Add reverse polarity prevention

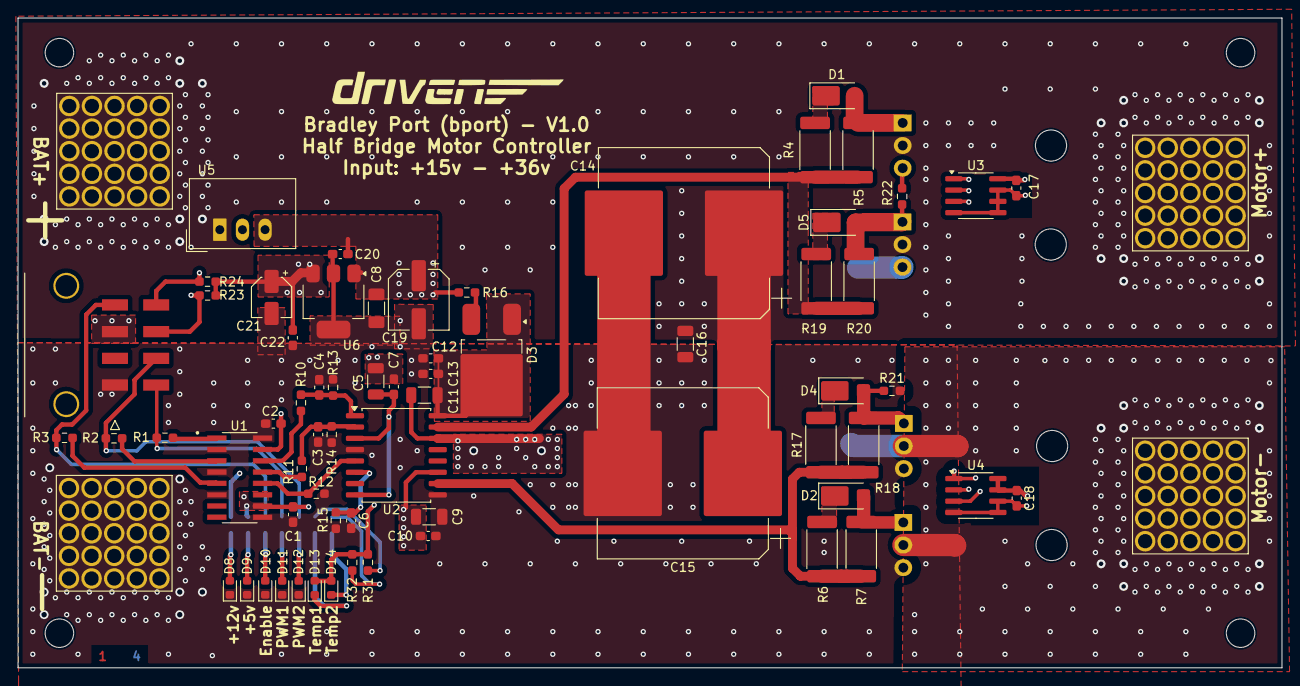
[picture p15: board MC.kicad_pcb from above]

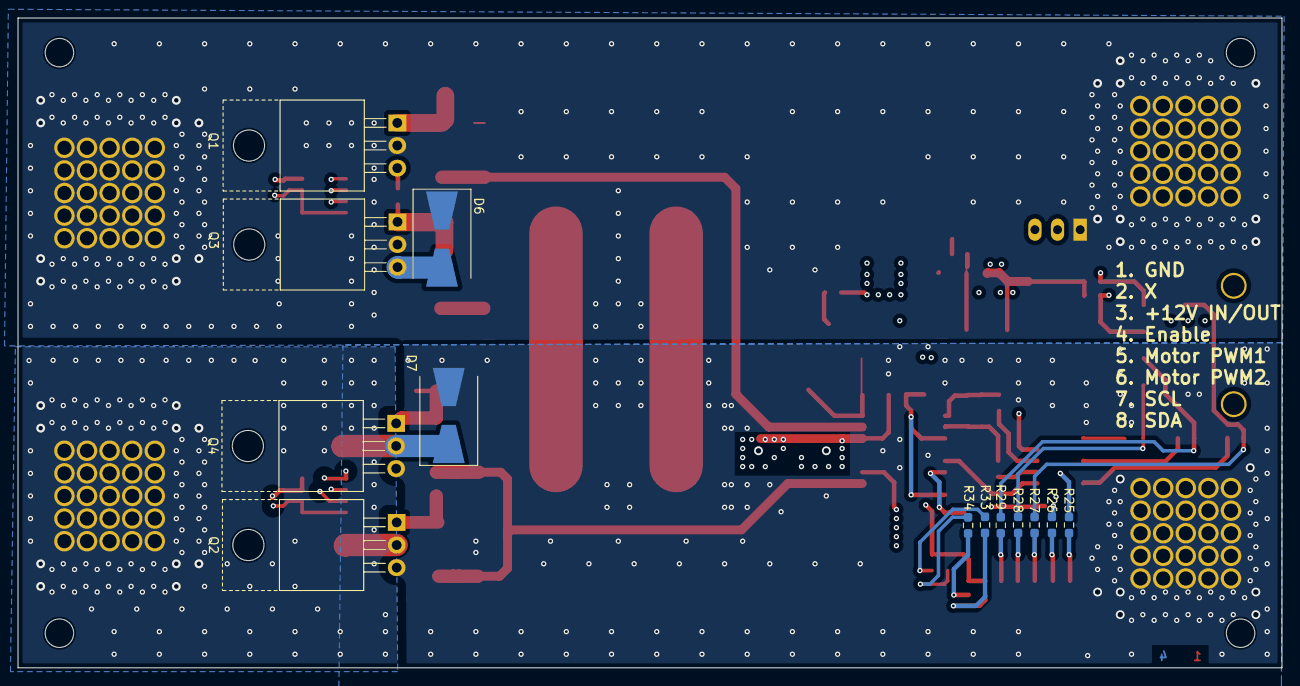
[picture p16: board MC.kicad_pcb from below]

Board: 4 copper layers, 142.0 x 73.0 mm, 82 parts (13 on the bottom side), 41 nets.
